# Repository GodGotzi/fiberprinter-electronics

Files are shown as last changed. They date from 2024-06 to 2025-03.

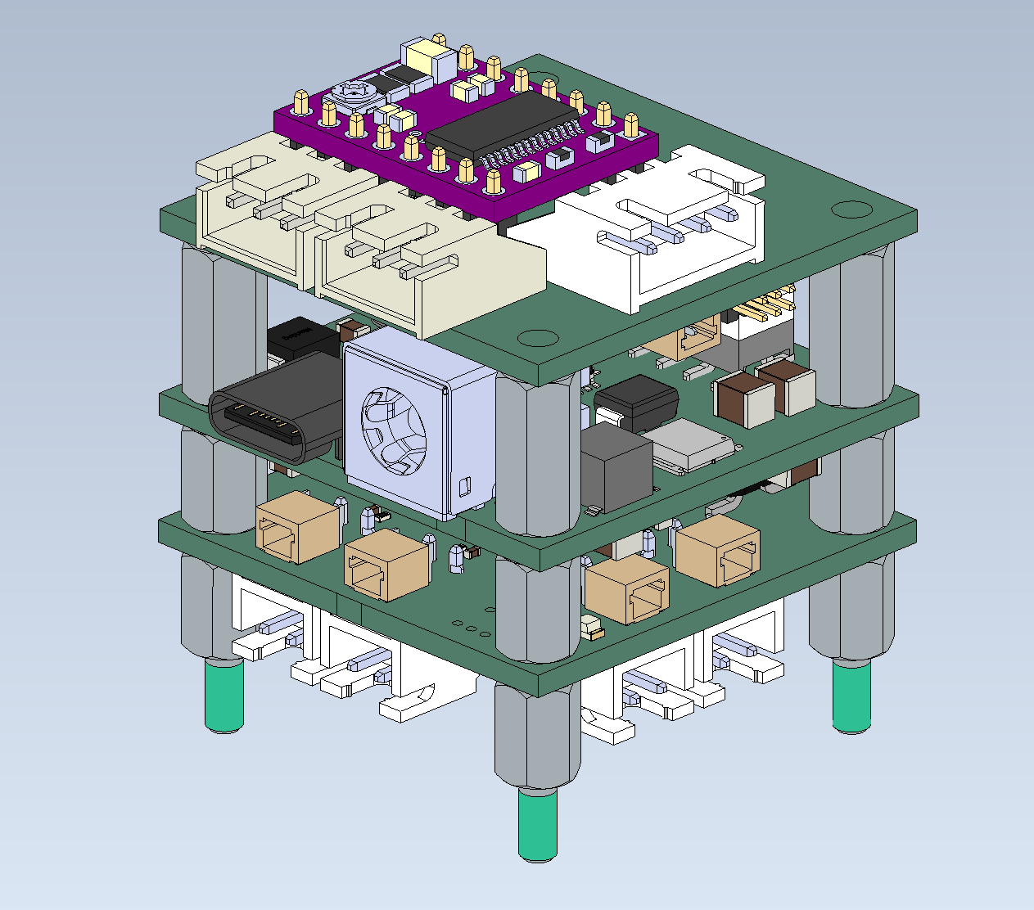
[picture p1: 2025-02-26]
2nd-mainboard-pcb/cad/bilder/simple.png

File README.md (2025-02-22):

# Fiberprinter Electronics

Dieses Repository enthält die Elektronikentwicklung für den faserverlegenden 3D-Drucker, der im Rahmen einer Diplomarbeit an der HTBLA Kaindorf entwickelt wird. Die Elektronik umfasst sowohl die Steuerung der Druckkopffunktionen als auch die Anbindung an das Hauptsystem mittels eines Raspberry Pi mit **Klipper-Firmware**.

## 📌 Projektübersicht

Das Ziel dieses Projekts ist die Entwicklung einer modularen und effizienten Steuerung für den Druckkopf, die über eine eigenentwickelte Platine mit einem **ATmega328** realisiert wird. Diese übernimmt spezifische Aufgaben, die über das Hauptsystem des Druckers nicht direkt gesteuert werden.

## ⚙️ Hauptkomponenten

### 1️⃣ **Steuerungshardware**
- **Raspberry Pi** mit Klipper-Firmware zur übergeordneten Steuerung
- **Eigenes Mainboard mit ATmega328** zur Ansteuerung folgender Komponenten:
  - Lüfter
  - BL Touch (Autoleveling-Sensor)
  - Servo
  - Schrittmotor
  - Temperatursensoren
- **Breakout-Board für den ATmega2560**, das Test- und Messpunkte sowie einen Bootloader enthält
- **FT232RL** als USB-to-Serial-Adapter für die Kommunikation mit dem ATmega2560
- **Reset-Button** zur einfachen Rücksetzung des Systems

### 2️⃣ **Firmware & Kommunikation**
- Der **ATmega328** wird von der Klipper-Firmware auf dem Raspberry Pi über USB angesprochen
- Kommunikation erfolgt über **serielles Protokoll**
- Entwicklung einer **angepassten Firmware für den ATmega328**, um die spezifischen Druckkopf-Funktionen auszuführen

### 3️⃣ **Software**
- Python-Skript zur **Integration der Steuerung in Klipper**
- Implementierung eines Protokolls zur **Steuerung der Hardware aus Klipper heraus**
- Zusammenarbeit mit der **Slicing-Software**, um die gezielte Faserverlegung zu ermöglichen

## 🛠️ Entwicklungsteam

- **Jan Traußnigg** – Elektronikdesign & Firmware
- **Nico Hütter** – Konstruktion, Aufbau & Testung
- **Elias Gottsbacher** – Slicing-Software & Software-Integration

## 📜 Lizenz

Dieses Projekt steht unter der **MIT-Lizenz**. Weitere Details sind in der Datei `LICENSE` zu finden.

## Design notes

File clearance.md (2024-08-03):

Sure, let's define both the minimum clearance and track width for each voltage and data line, adhering to industry standards for safe and reliable operation in a controlled environment (within a housing).

### 1. **12V DC**
- **Minimum Clearance:** 0.2 mm
- **Minimum Track Width:** 0.3 mm
- **Argument:** For 12V DC circuits, a clearance of 0.2 mm ensures safety against short circuits and arcing according to IEC 60950-1. The track width of 0.3 mm is chosen to handle the current typically associated with 12V DC circuits, providing a balance between electrical performance and manufacturability.

### 2. **5V DC**
- **Minimum Clearance:** 0.2 mm
- **Minimum Track Width:** 0.2 mm
- **Argument:** For 5V DC circuits, maintaining a 0.2 mm clearance aligns with IEC 60950-1 standards, ensuring electrical safety. A track width of 0.2 mm is sufficient for the low current levels typically found in 5V circuits, ensuring reliable operation and ease of manufacturing.

### 3. **3.3V DC**
- **Minimum Clearance:** 0.1 mm
- **Minimum Track Width:** 0.15 mm
- **Argument:** For 3.3V DC circuits, a 0.1 mm clearance is appropriate given the low voltage and controlled environment, adhering to industry norms. The track width of 0.15 mm is adequate for the lower current levels in 3.3V circuits, ensuring signal integrity and reliability.

### 4. **5V I2C Data**
- **Minimum Clearance:** 0.2 mm
- **Minimum Track Width:** 0.2 mm
- **Argument:** For I2C data lines operating at 5V, a 0.2 mm clearance ensures minimal risk of crosstalk and signal interference, crucial for reliable communication. The track width of 0.2 mm supports the low current typically associated with data lines while maintaining signal integrity.

### 5. **5V Differential I2C Data**
- **Minimum Clearance:** 0.2 mm
- **Minimum Track Width:** 0.2 mm (each line in the pair)
- **Argument:** For differential I2C data lines at 5V, a 0.2 mm clearance helps prevent crosstalk between pairs and other signal paths. Each line in the differential pair should have a track width of 0.2 mm to ensure consistent impedance and reliable differential signaling.

### Summary of Chosen Clearances and Track Widths:
- **12V DC:** 
  - **Clearance:** 0.2 mm
  - **Track Width:** 0.3 mm
- **5V DC:**
  - **Clearance:** 0.2 mm
  - **Track Width:** 0.2 mm
- **3.3V DC:**
  - **Clearance:** 0.1 mm
  - **Track Width:** 0.15 mm
- **5V I2C Data:**
  - **Clearance:** 0.2 mm
  - **Track Width:** 0.2 mm
- **5V Differential I2C Data:**
  - **Clearance:** 0.2 mm
  - **Track Width:** 0.2 mm (each line in the pair)

These specifications are chosen to ensure the minimum necessary sizes for clearances and track widths, balancing safety, performance, and manufacturability for your design within a controlled environment.

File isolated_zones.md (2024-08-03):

### Potential Risks of Isolated Copper Fills on a PCB

1. **Electromagnetic Interference (EMI):**
   - Acts as antennas, increasing EMI emissions.
   - Can interfere with the PCB and nearby electronic devices.

2. **Signal Integrity Issues:**
   - Causes impedance mismatches and reflections.
   - Leads to signal integrity problems.

3. **Thermal Management Problems:**
   - Creates hot spots or uneven thermal distribution.
   - Can cause overheating of components.

4. **Manufacturing Defects:**
   - Problems with etching and plating processes.
   - May result in incomplete etching or plating voids.

5. **Electrochemical Migration:**
   - Accumulation of moisture and contaminants.
   - Increases the risk of short circuits.

6. **Mechanical Stress:**
   - Creates mechanical stress points, especially during thermal cycling.
   - Can lead to delamination or cracking.

7. **Increased Capacitance:**
   - Introduces unwanted capacitance.
   - Affects performance of high-speed signals and RF circuits.

8. **Potential for Floating Copper:**
   - Unconnected copper fills can float electrically.
   - Leads to unpredictable circuit behavior.

### Mitigation Strategies
- Ensure copper fills are properly connected to a reference plane (e.g., ground).
- Carefully consider the placement of copper fills in the PCB design.
- Conduct thorough design reviews and simulations to identify and address potential issues before manufacturing.

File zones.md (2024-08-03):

### Summary of Filled Zones in PCB Design:

**Filled Zones Overview:**
- **Definition:** Areas on a PCB layout filled with copper, typically used for ground planes, power planes, and large conductive areas.
- **Purpose:** Improve electrical performance, thermal management, and mechanical strength of the PCB.

**Importance in EMI Reduction:**
1. **Minimizing Loop Areas:**
   - Ground planes provide a low-impedance return path for signals, reducing loop areas and radiated EMI.
2. **Providing Shielding:**
   - Ground planes act as shields, blocking external EMI and preventing internal signals from radiating out.
3. **Improving Signal Integrity:**
   - Maintain consistent impedance for high-speed signals and reduce noise.
4. **Reducing Crosstalk:**
   - Continuous reference planes help minimize crosstalk between adjacent signal traces.

**Best Practices for Using Filled Zones:**
- **Use Solid Ground Planes:**
  - Prefer solid ground planes for maximum EMI reduction and signal integrity.
- **Keep Signal and Return Paths Close:**
  - Route high-speed signals over continuous ground planes.
- **Utilize Stitching Vias:**
  - Connect ground planes on different layers with stitching vias to reduce impedance.
- **Avoid Splits in Ground Planes:**
  - Ensure ground planes are not interrupted by signal traces or other discontinuities.
- **Place Decoupling Capacitors:**
  - Position decoupling capacitors close to power pins of ICs to mitigate high-frequency noise.
- **Isolate Noisy Components:**
  - Keep noisy components away from sensitive analog circuits and use ground planes to shield them.

### Recommendations:
- **For EMI Reduction:**
  - Use solid copper pours for ground planes.
  - Ensure continuous and unbroken ground planes beneath signal traces.
  - Implement stitching vias to enhance grounding and reduce EMI.
- **For Overall Performance:**
  - Combine ground and power planes to create a stable electrical environment.
  - Maintain proper clearance settings and use thermal reliefs for component pads.

By implementing these practices, you can significantly enhance the EMI performance and overall functionality of your PCB designs.

TO FIX THE ERROR "ISOLATED COPPER FILLS" TURN ON "REMOVE ISLANDS" IN FILLING ZONE.

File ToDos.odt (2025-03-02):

ToDo

Wie viel ohm hat motor

Is mosfet zu langsam?

Max strom 100mA -> wenn man einfach einen mosfet mit max 1a nimmt wird der Gate kondensator auch kleiner dann schaltet er schneller

Sensor werte 1. Ordnung reicht normal, sonst gibt’s ja eh die möglichkeit vom digitalen filtern no

Jede sekunde messwert nehmen

Equididante sampling rate

Wird stepper schritte verlieren? Wie kurz werden die schritte?

Worst case: faser fängt 1mm zu spät an

Die freien general purpose io pins nach außen legen

Mit oszilloskopo pwm ausgang testen

Checken ob bauteile verfügbar sind jlcpcb

Stencil

Display raspi

vorschlag

wir haben 80er serie smd bauteile in der schule zur verfügung

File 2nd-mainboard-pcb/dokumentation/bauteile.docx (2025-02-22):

Stückliste Bestellung 15.1.2025

USB-C Stecker: 2x

https://www.digikey.at/en/products/detail/gct/USB4085-GF-A/9859662

Atmega 328P

https://www.digikey.at/de/products/detail/microchip-technology/ATMEGA328PB-AU/5638812

USB/Serial Wandler

https://www.digikey.at/en/products/detail/ftdi-future-technology-devices-international-ltd/ft232rl-reel/1836385

optional 5V 3V3 converter

https://www.digikey.at/de/products/detail/mornsun-america-llc/F0503XT-1WR3-TR/13617558

LED

https://www.digikey.de/en/products/detail/w%C3%BCrth-elektronik/151031VS06000/4489988

switch

https://www.digikey.de/en/products/detail/panasonic-electronic-components/EVQ-Q2Y02W/762910

oscillator

https://www.digikey.at/de/products/detail/ecs-inc/ECS-160-18-4X-CKM/12349451

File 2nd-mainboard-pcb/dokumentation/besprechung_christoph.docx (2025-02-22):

Besprechung christoph scheucher

Schaltfrequenzen wegpuffern

Lötpdastellen fuer ios und andere

Atmega328 – aurct-nd

Okay kleiner neuanfang: was k“habe ich heute mit dem scheucher geredet? Wir haben angefangen dmait, dass er mir seine platinbe, die er f“ur den robocuip entwickelt hat gezeigt hat, mir tipps gegeben hat und betont hat, dass ich mich bei fragen jederzeit bei ihm melden k“onnte. Sehr nett

Kommen wir aber gleich zu den tipps, an die ich mich erinnern m“ochte. Erstens: w“ahle verschieden kondensatoren gro:ossen aus, da sie unterschiedliche frequenzen puffern. Versuche sie so zu w’halen, dass die deine schaltfrequenz wegpuffern. Elektrolyt kondensatoren werden warm, deswegen hat er von diesen keine verwendet. Ausserdem hat mer mir empfohlen, anschluesse die mir zur verf“ugung stehen, welche ich aber in meinem projekt nicht unbedingt brauche trotzdem als l“otpad auszuf“uhren um diese f“ur sp“atere optionale debugging zwecke benutzen zu k“onnen.

Meine n“achsten schritte werden jetzt jedenfalls sein 12v leistung zum mainboard mitzuliefern, wie auch immer das realisiert wird. Eventuell kann usb-c sogar 12v „ubergeben, da muss vorher halt geschaut werden wie das funktionieren k“onnen. Ausserdem muss ich mir den strom anschauen, welcher der raspberry pi liefert und welchen verbrauch ich am druckkopf habe. Dadurch, dass ich jetzt ja auch noch einen schrittmotor am druckkopf ansteuern muss „andern sich ein paar dinge. Zudem, k“onnte idch vielleicht sogar 5v zu 12v konvertieren? Wenn nicht, k“onnte es kompliziert werden, dann muss ich schauen ob der raspberry pi einen 12v ausgang hat und mit welchem kabel ich das hinauf verbinde. Die fans k“onnten auch 12v gebrauchen, ist aber kein unbedingtes muss

Auf jeden fall sollte ich als alternative 5v fans heraussuchen.

Dann sollte ich schauen, ob der schrittmotor eh mit einem normalen motor driver angesteuert werdenkann. Dann sollte ich nico um die neuste konstruktion bitten, um einzusehen, wo ich die platine montieren kann und wie viel platz ich habe. Zudem ob odie headerpins f“ur die fans 01x02 geiignet sind tht vertical/horizontal oder ob da vielleicht sogar smd m“oglich w“are. Dann m“ussten wir halt die temperatursensor kabeln neu konfektionieren, aber das w“ar ja okay.

Scund ausserdem kann ich mich sollte ich mich nach eine mbeschleunigungssensor umschauen.

Offen bleibt zudem die frage, ob wir das heat element dann auch mit der printhead pcb ansteuern oder vom mainboard damit zum printhead gehen. Wenn ja, dann k“onnten wir gleich nach einer l“sung suchen bei der wir die leitung f’ur das heatbreak und die 12v leitung mit einem kabel rauf verbinden.

Zudem sollte ich ein neues kicad project f“ur das raspi shield anfertigen, da es sich jett viel vom i2c rapsi shield unterscheidet.

Trotzdem sollte ich einen stepper driver noch auf dem raspi shield verbauen, nur um sicher zu gehen…. Da hab ich sowieso platz.

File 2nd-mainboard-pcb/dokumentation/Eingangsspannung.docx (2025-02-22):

Eingangsspannung-Kalkulierung

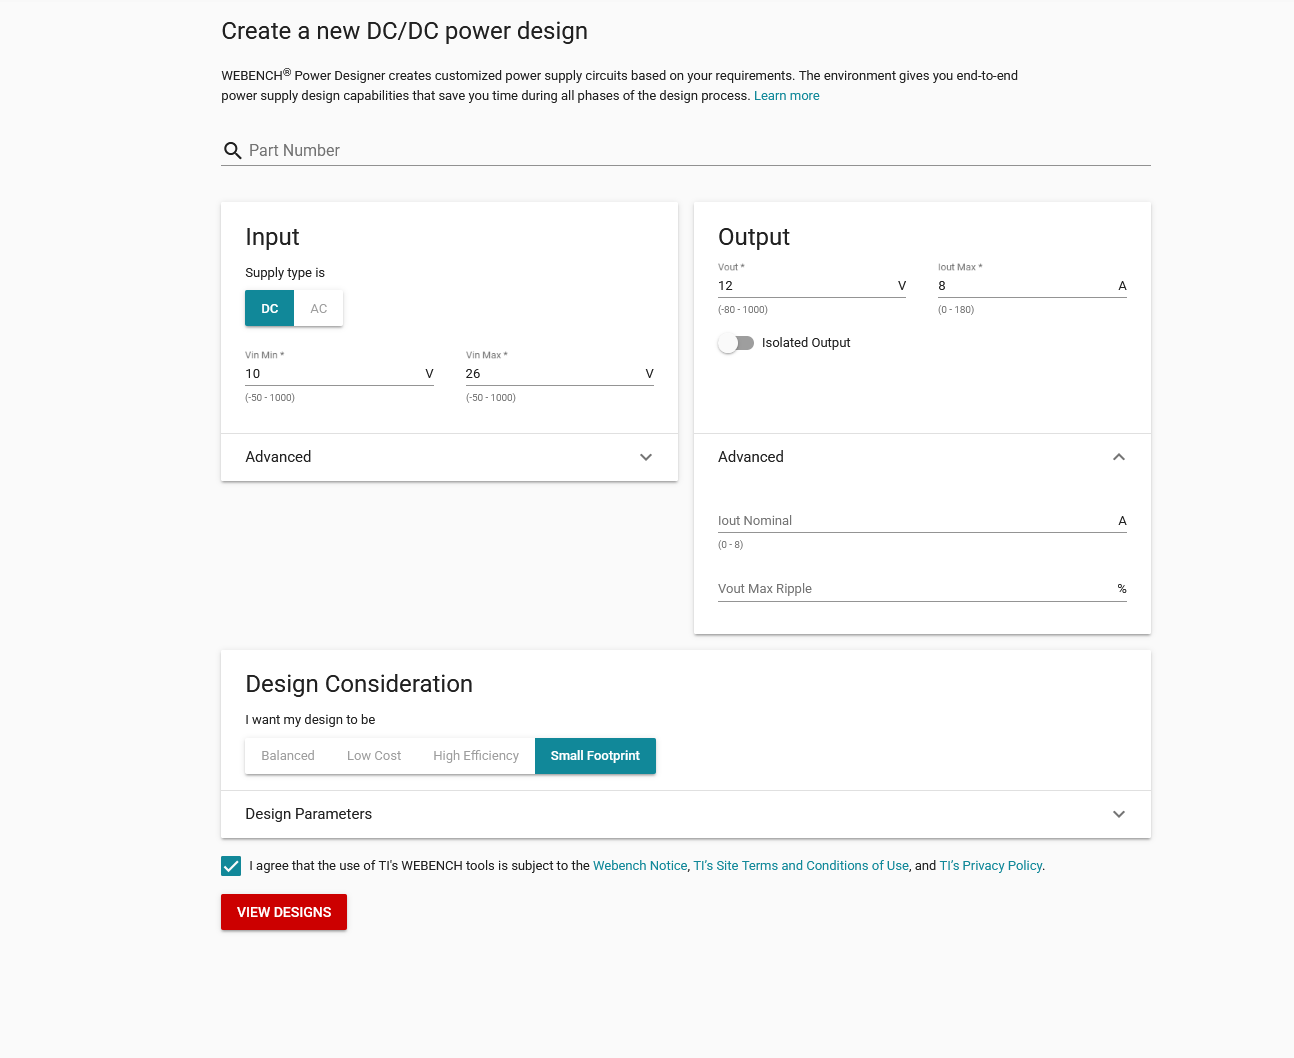
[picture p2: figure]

https://webench.ti.com/power-designer/switching-regulator?powerSupply=0

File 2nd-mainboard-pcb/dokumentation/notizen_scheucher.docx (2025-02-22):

Zusammenfassung der Notizen

Notizen

1. Gespräch mit Scheucher:
  - Präsentation seiner Platine für RoboCup.
  - Hinweise und Angebot für Unterstützung bei Fragen.
  - Freundliche Atmosphäre.
2. Wichtige Tipps von Scheucher:
  - Kondensatorwahl:
    - Unterschiedliche Größen puffern verschiedene Frequenzen.
    - Kondensatoren sollten auf die Schaltfrequenz abgestimmt sein.
    - Vermeidung von Elektrolytkondensatoren wegen Wärmeentwicklung.
  - Debugging-Optionen:
    - Zusätzliche Lötpads für Anschlüsse, auch wenn diese zunächst nicht benötigt werden.

To-Do-Liste

1. Elektrische Versorgung:
  - 12V Versorgung zum Mainboard integrieren.
  - Überprüfen, ob USB-C 12V übertragen kann.
  - Alternativen prüfen: 5V zu 12V Konverter oder direkte 12V vom Raspberry Pi.
2. Verbrauchsanalyse:
  - Strombedarf des Raspberry Pi und des Druckkopfs analysieren, insbesondere mit zusätzlichem Schrittmotor.
3. Komponentenwahl:
  - Lüfter auf 5V-Basis als Alternative heraussuchen.
  - Prüfen, ob der Schrittmotor mit einem Standard-Motortreiber betrieben werden kann.
4. Designanpassung:
  - Aktuelle Konstruktion von Nico einholen:
    - Platz für die Platine.
    - Ausrichtung und Position der Header-Pins (01x02, THT vertikal/horizontal, SMD möglich?).
5. Temperatursensorkabel:
  - Überarbeitung und Konfektionierung.
6. Sensoren:
  - Recherche nach einem Beschleunigungssensor für den Druckkopf.
7. Wärmeeinbindung:
  - Klären, ob das Heizelement über die Printhead-PCB oder direkt vom Mainboard angesteuert wird.
8. Platinenerstellung:
  - Neues KiCad-Projekt für das Raspberry Pi Shield anlegen:
    - Anpassungen an den veränderten Anforderungen (Unterschiede zum I2C-Shield).
    - Einbindung eines Stepper Drivers auf dem Shield.

Zusammenfassung der Herausforderungen

- Integration zusätzlicher Komponenten (Schrittmotor, Lüfter).
- Sicherstellung der elektrischen Versorgung (12V und 5V).
- Platz- und Designanforderungen klären.
- Debugging und erweiterte Funktionalität durch Zusatzoptionen berücksichtigen.

Die strukturierte Planung ermöglicht es, die nächsten Schritte effizient zu koordinieren und gezielt an den Herausforderungen zu arbeiten.

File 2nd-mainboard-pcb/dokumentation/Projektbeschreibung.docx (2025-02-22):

# Projektbeschreibung

Druckkopf für einen 3D Drucker. Am Druckkopf sind angebracht:

- 4 Lüfter
- 1 Servo
- 1 Schrittmotor
- 4 Temperatur sensoren

Zur Ansteuerung des Druckkopfes wird ein Raspberry Pi verwendet, auf welchem die Firmware Klipper installiert ist. Dieser kommuniziert mit einer USB Verbindung mit dem Mainboard des 3D Druckers.

Am Druckkopf ist ein zweites eigenentwickeltes Mainboard, das auch mit USB zum Raspbberry Pi verbunden ist.

Auf dem zweiten Mainboard ist der ATMEGA328P-AN, um das Schaltbild zu entwickeln werden folgende schritte gemacht:

### 1. Stromversorgung

- Spannungsregler: Raspberry Pi12V -> Spannungsregler, um die Spannung für den ATmega328 auf 5V zu senken
- Bypass-Kondensatoren: stabile Stromversorgung -> Kondensatoren (z. B. 0.1 µF und 10 µF) nahe dem ATmega328.

### 2. ATmega328 Schaltung

- Taktgeber: Quarz (z. B. 16 MHz) mit zwei 22pF-Kondensatoren, um stabil zu laufen
- Reset-Pin: Reset-Pin mit Taster und einem Pull-up-Widerstand (z. B. 10 kΩ), damit du den ATmega328 manuell zurücksetzen kannst.

### 3. USB-Kommunikation

- Um eine Verbindung zum Raspberry Pi über USB herzustellen, benötigst du einen USB-to-Serial-Wandler MCP2200
- Verbinde die UART-Pins (RX/TX) des ATmega328 mit dem Wandler.

### 4. Ansteuerung der Komponenten

- Lüfter: Die 4 Lüfter benötigen entweder PWM-Pins des ATmega328
- Servo: Für den Servo brauchst du einen PWM-Ausgang.
- Schrittmotor: Zur Steuerung eines Schrittmotors DRV8825
- Temperatursensoren: Die 4 Temperatursensoren (vermutlich NTCs oder Thermistoren) können an analogen Eingängen des ATmega328 angeschlossen werden.

### 5. Bauelemente und Verbindungen

- Pull-up/Pull-down Widerstände: Wenn du digitale Eingänge verwendest, vergiss nicht, entsprechende Widerstände (typischerweise 10kΩ) hinzuzufügen.
- Schutzdiode: Du kannst eine Schutzdiode (z. B. 1N4007) einbauen, um den ATmega vor Rückstrom zu schützen.

### 6. Kommunikation mit dem Raspberry Pi

- USB-Kabel: Stelle sicher, dass du die USB-Verbindung vom ATmega328 zum Raspberry Pi korrekt verdrahtest. Die USB-Leitung muss über den USB-zu-Seriell-Wandler laufen.

### 7. PCB Design

- Nachdem du den Schaltplan erstellt hast, musst du entscheiden, wie du das PCB layouten möchtest, um die Verbindungen zwischen den Bauteilen herzustellen.

Offene Fragen

Kann man den Atmega auch über die USB Schnittstelle programmieren?

Muss die Kommunikation über USB gehen?

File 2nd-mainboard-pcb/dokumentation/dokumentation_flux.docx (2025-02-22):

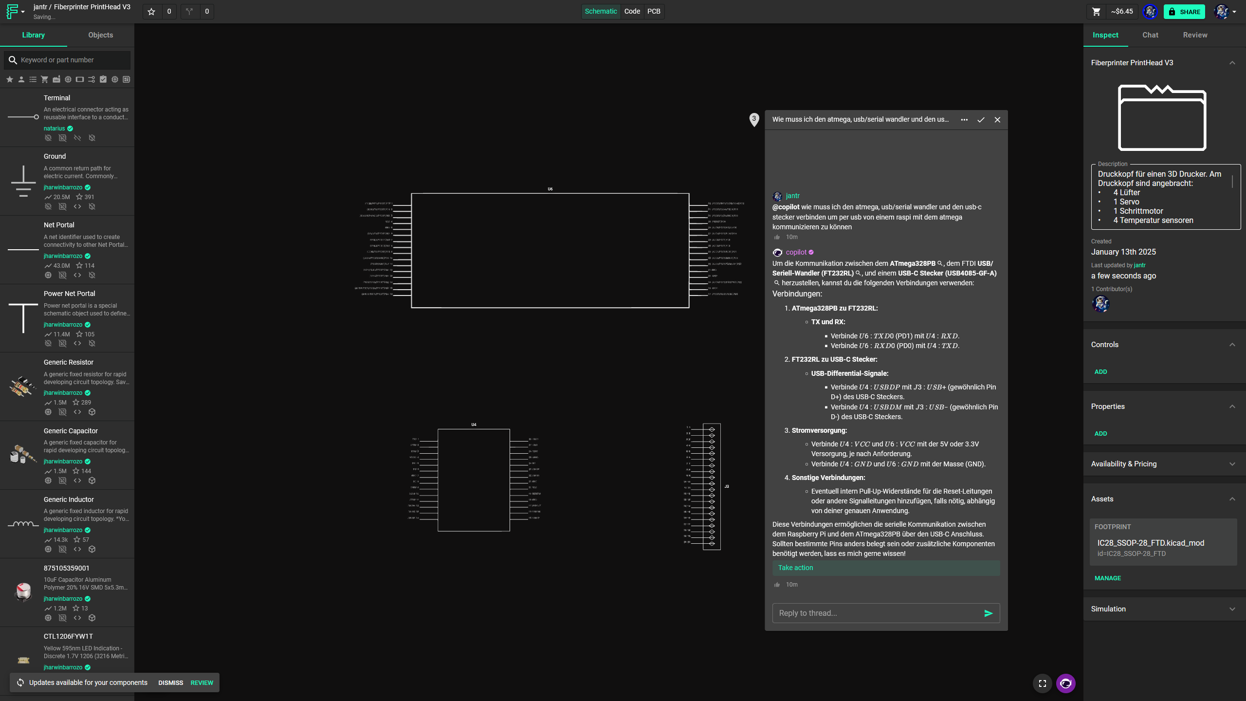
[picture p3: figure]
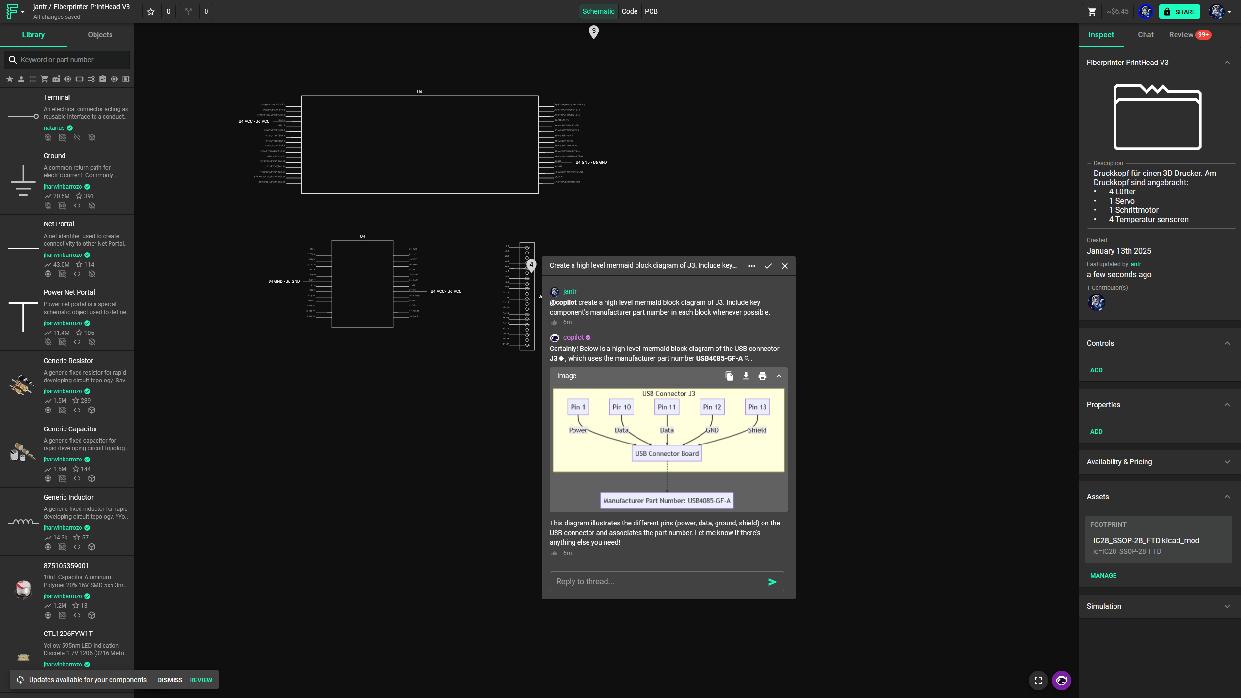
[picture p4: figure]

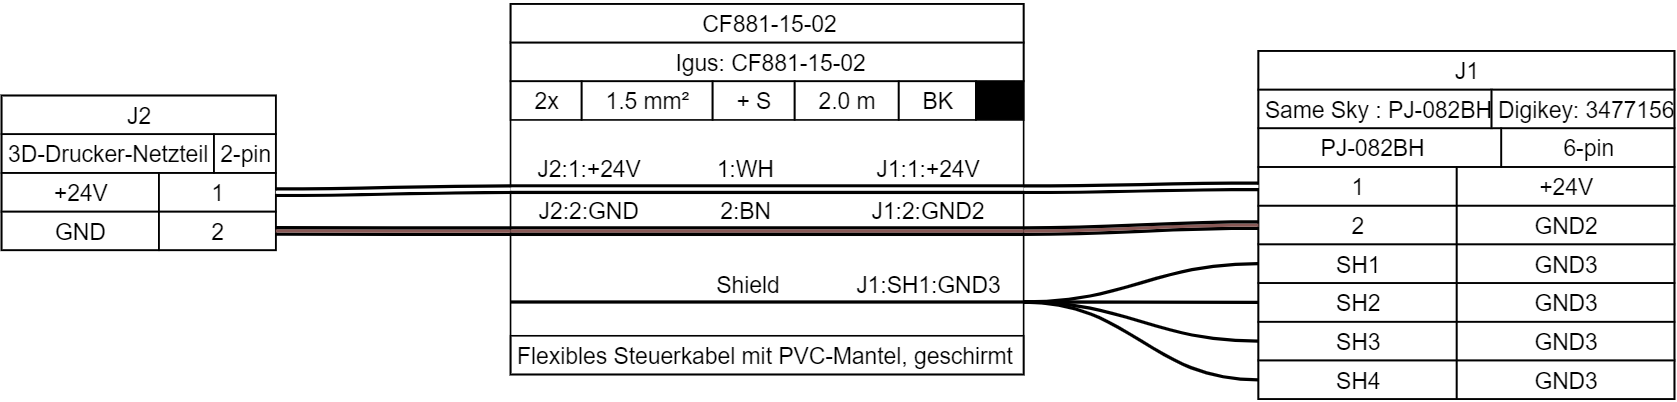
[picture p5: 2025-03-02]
usbstick/elektronik/wireviz/Verbindung_Platine_3D_Drucker.png

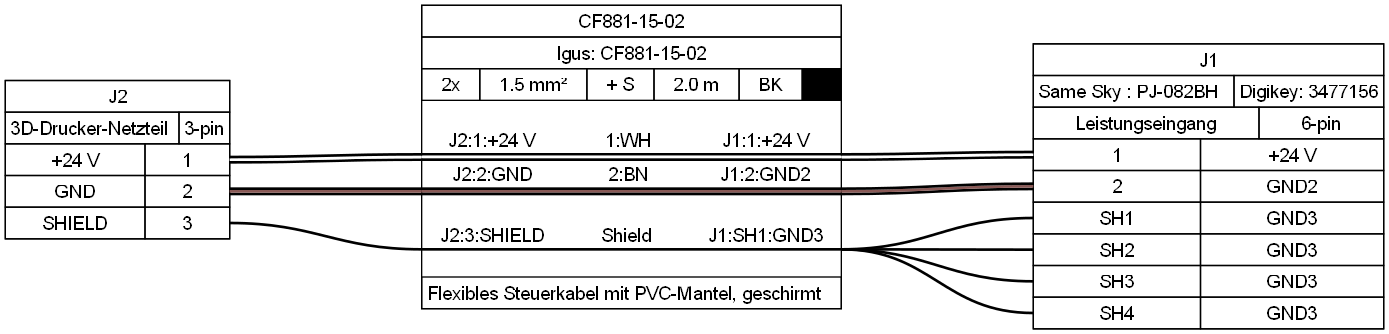
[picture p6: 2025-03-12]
2nd-mainboard-pcb/wireviz/png/platine_drucker.png

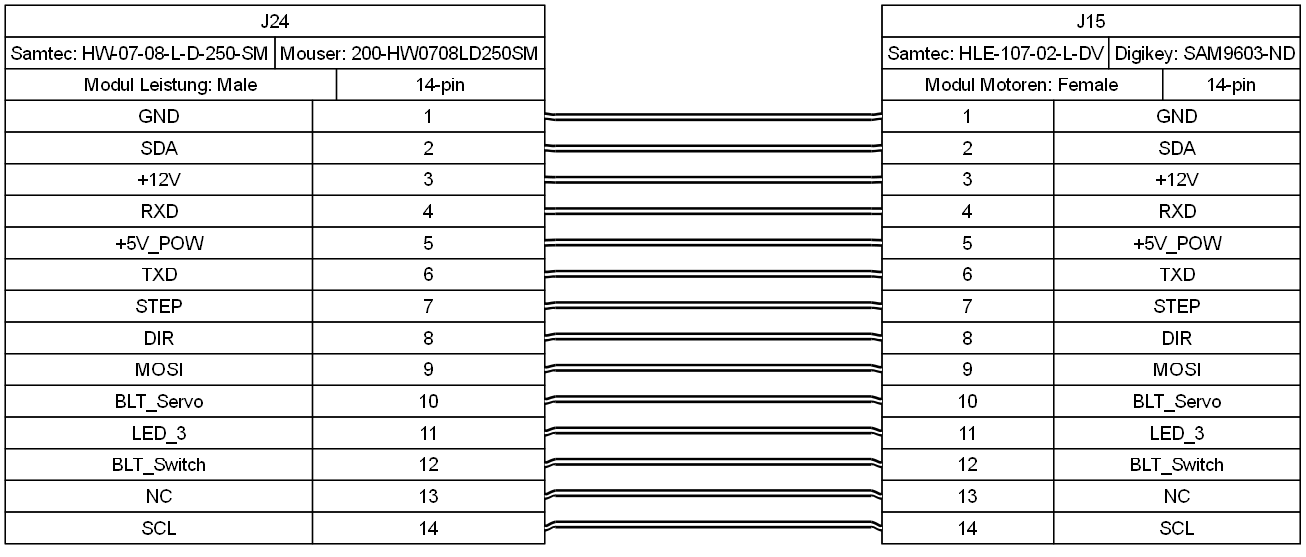
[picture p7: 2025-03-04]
usbstick/elektronik/wireviz/leistung_motoren.png

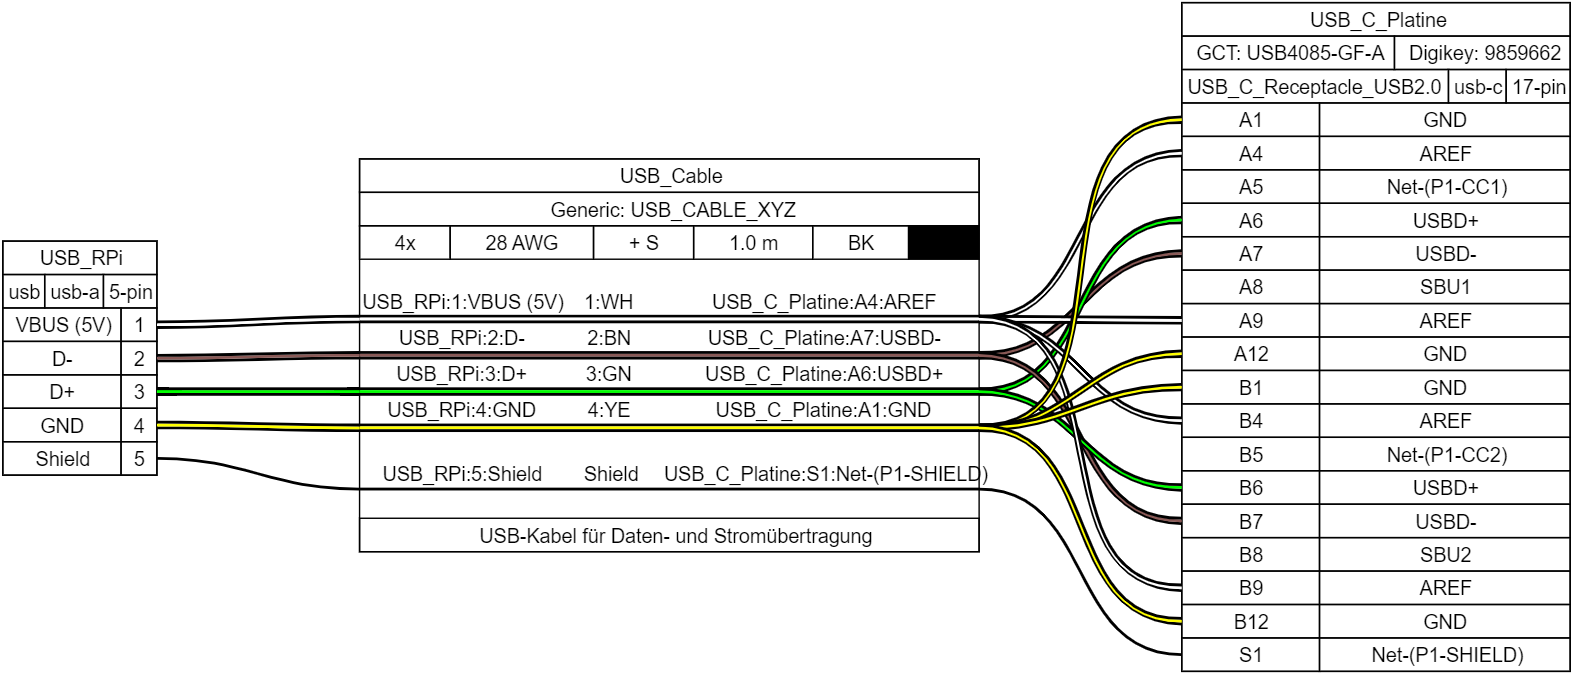
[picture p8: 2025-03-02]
usbstick/elektronik/wireviz/Verbindung_Platine_Raspi.png

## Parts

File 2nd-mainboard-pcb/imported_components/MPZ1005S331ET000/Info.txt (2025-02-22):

Eine Ferritperle dient dazu, hochfrequente Störungen auf der Versorgungsleitung zu unterdrücken, indem sie bei diesen Frequenzen eine hohe Impedanz aufweist. Dadurch wird das Rauschen reduziert und die Stabilität der Versorgungsspannung im System verbessert.

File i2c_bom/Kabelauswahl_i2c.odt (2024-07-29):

Variante 1: Kabel auf eBay/Amazon bestellen (Kein Datenblatt) und Buchse dazukaufen

Vorteil: Einheitliches Buchsensystem (jst ist übliche 3D Drucker Buchse), schnelle Lieferung

Nachteil: Nicht konfektioniert, Buchse muss angelötet/gecrimped werden

Kabelauswahl

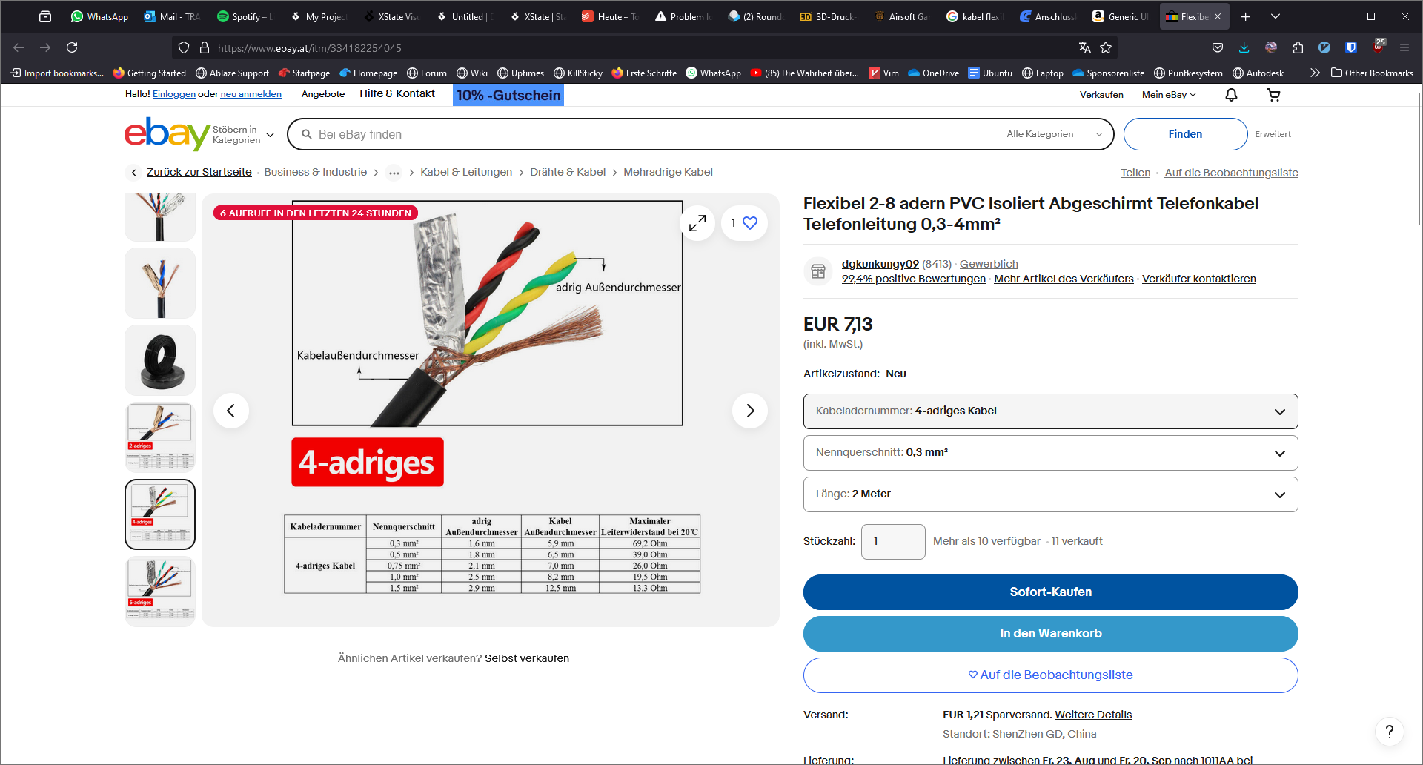
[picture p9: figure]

https://www.ebay.at/itm/334182254045

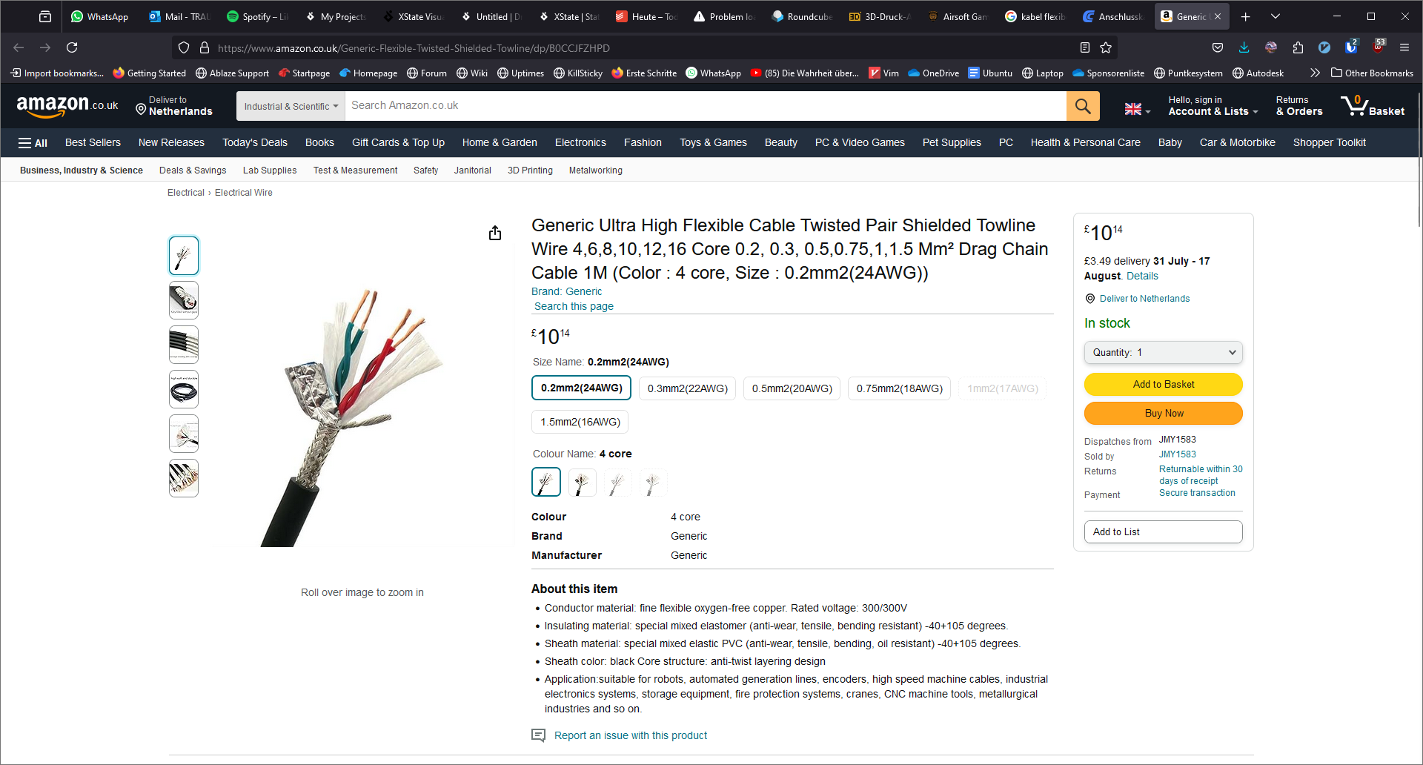
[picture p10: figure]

https://www.amazon.co.uk/Generic-Flexible-Twisted-Shielded-Towline/dp/B0CCJFZHPD

Buchsenauswahl

Normale Buchse Set

Nachteil: Nicht gewinkelt, erschwert den Einbau bei Platine

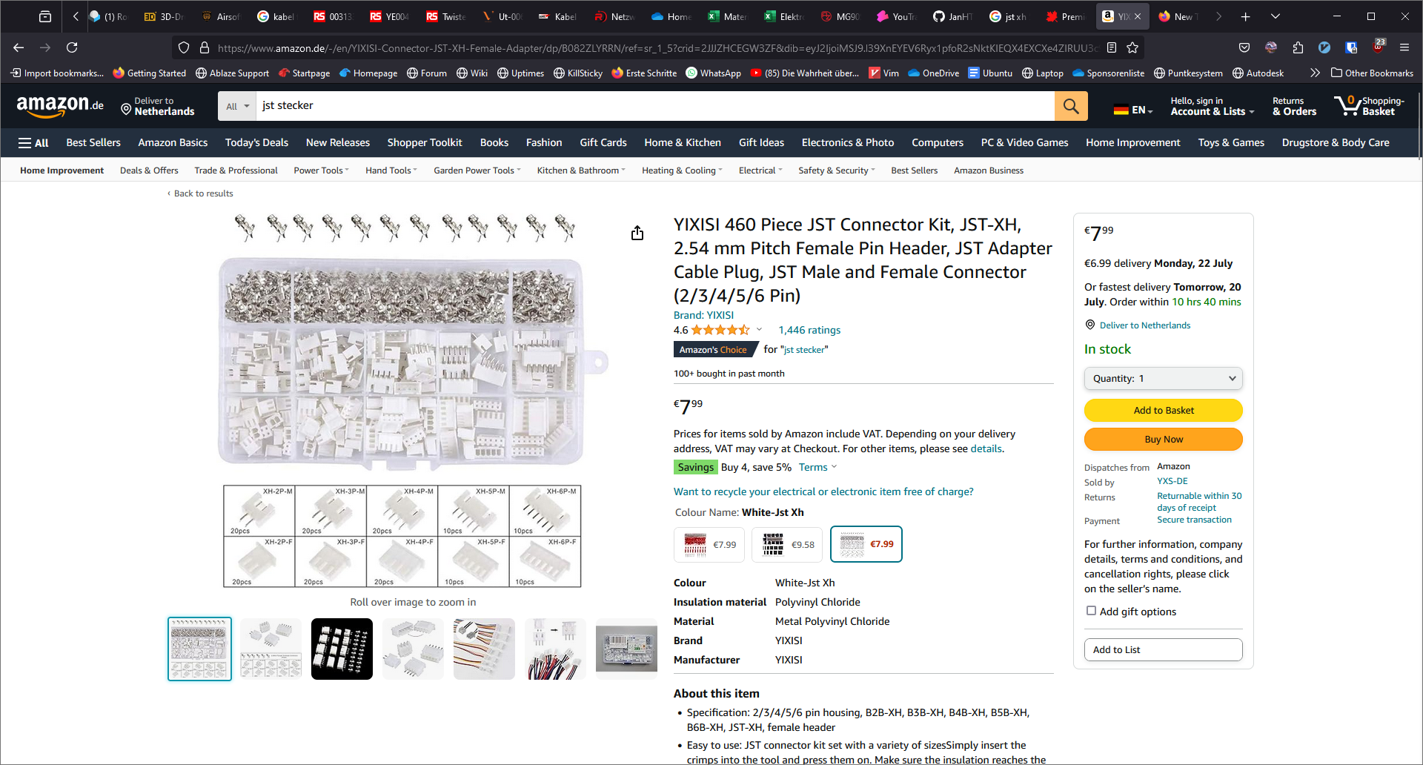
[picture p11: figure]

https://www.amazon.de/-/en/YIXISI-Connector-JST-XH-Female-Adapter/dp/B082ZLYRRN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

Problem: 99% der rechtwinkligen Buchsen haben 2mm Pitch und wir möchten 2,54mm Pitch

Warum 2,54mm: standart Rastermaß ist 2,54, man kann normale breadboards und jumper kabeln verwenden

Lösung 1: Eine Seite auf Ebay bietet das an (wirkliche die einzige die wir gefunden habn)

Problem: Versand nicht nach Österreich

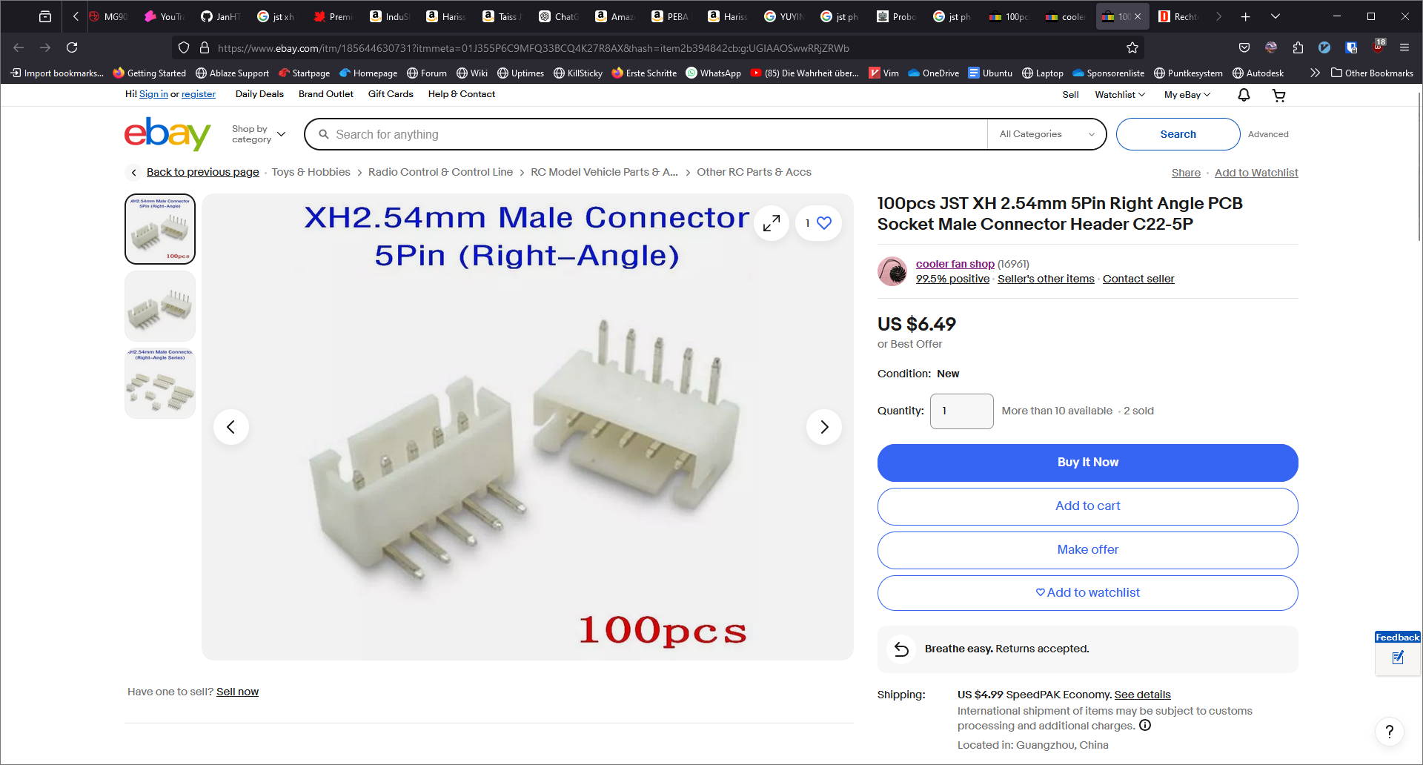
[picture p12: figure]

https://www.ebay.com/itm/185644630731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

Lösung 2: gewinkelte Jumper verwenden als Buchse für Platine

Anmerkung: Funktionalität muss erst getestet werden

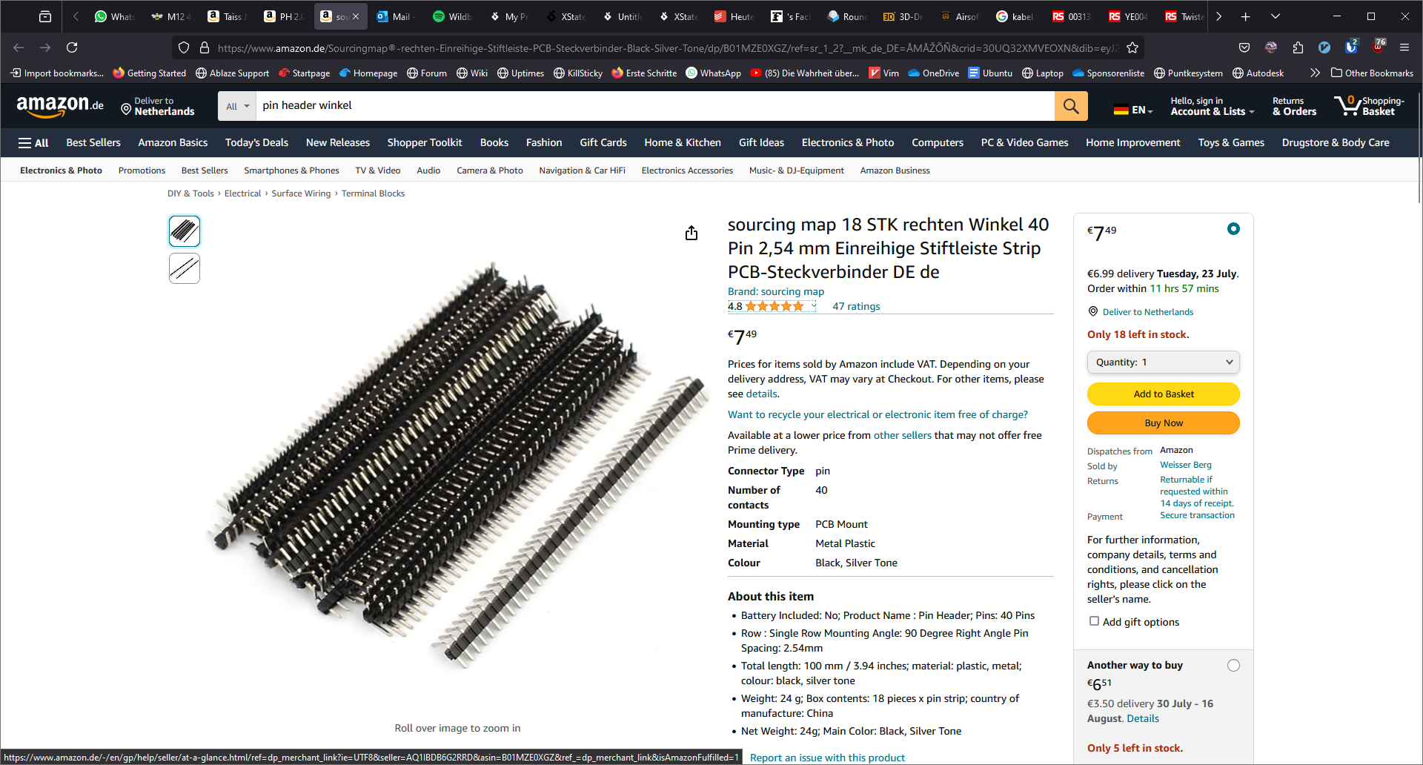
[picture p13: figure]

https://www.amazon.de/Sourcingmap%C2%AE-rechten-Einreihige-Stiftleiste-PCB-Steckverbinder-Black-Silver-Tone/dp/B01MZE0XGZ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 (https://www.amazon.de/Sourcingmap®-rechten-Einreihige-Stiftleiste-PCB-Steckverbinder-Black-Silver-Tone/dp/B01MZE0XGZ?__mk_de_DE=ÅMÅŽÕÑ)

Lösung 3: 2mm Pitch verwenden

Vorteil: Set, wo alles dabei ist (gewinkelte Buchse und gerade Stecker)

Nachteil: Nicht im standard-Rastermaß

Anmerkung: Irgendwo muss das aber Norm sein, so viel wie 2mm pitch winkel buchsen wir hier gefunden haben

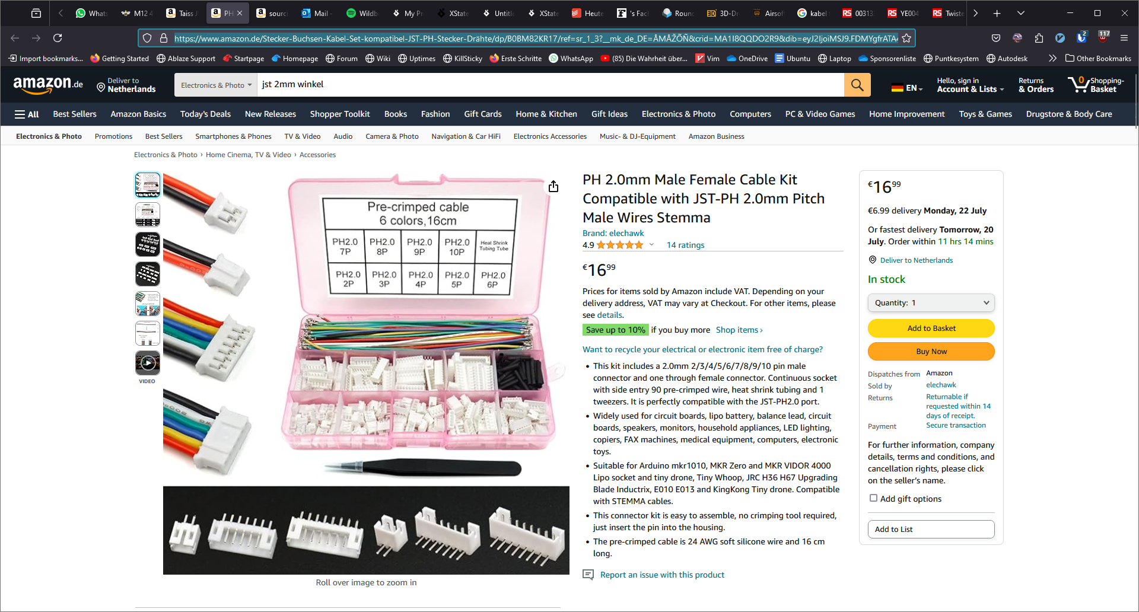
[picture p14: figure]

https://www.amazon.de/Stecker-Buchsen-Kabel-Set-kompatibel-JST-PH-Stecker-Dr%C3%A4hte/dp/B0BM82KR17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

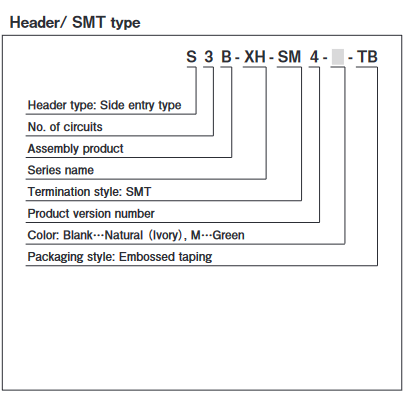
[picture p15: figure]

Variante 2: Fertiges Kabel mit Stecker bestellen

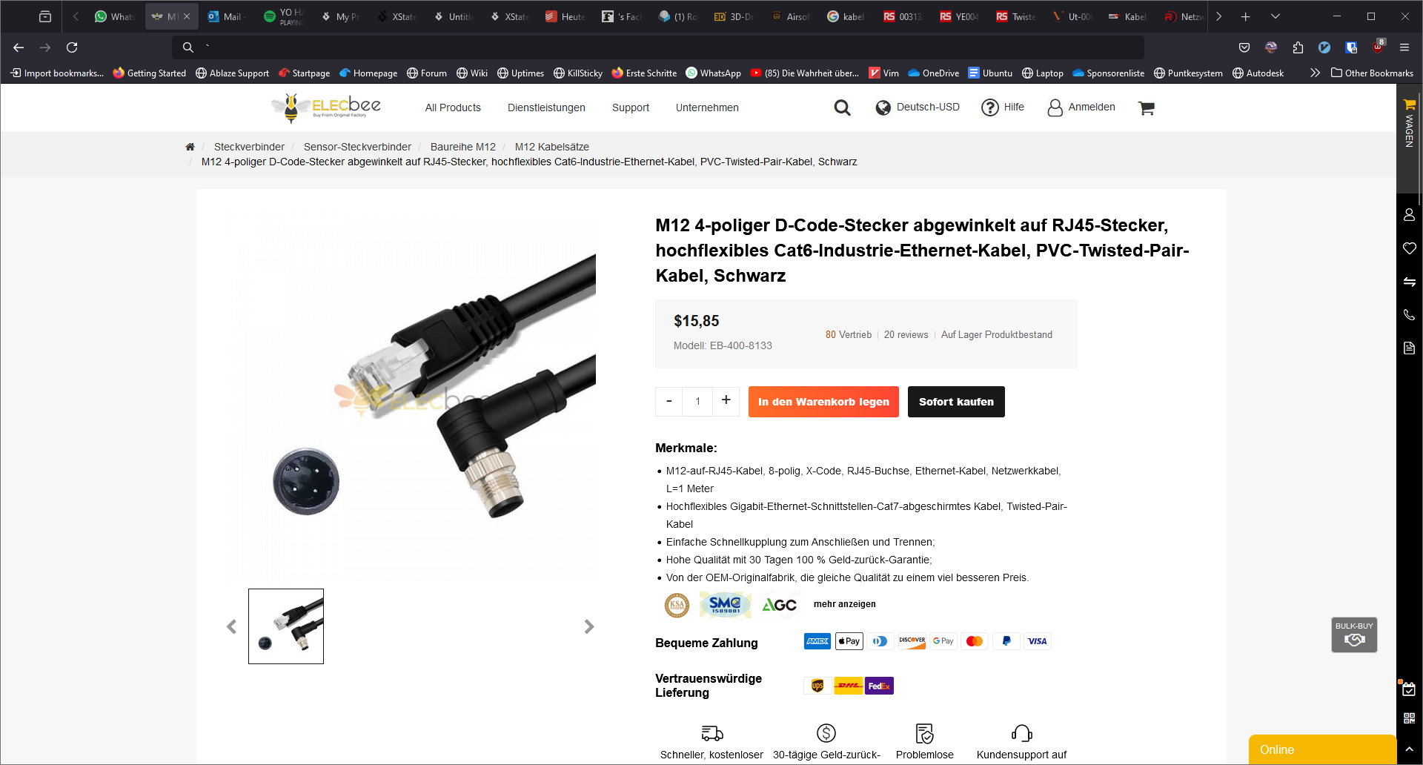
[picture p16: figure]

https://www.elecbee.com/de-54283-m12-4-pin-d-code-male-angled-to-rj45-male-high-flex-cat6-industrial-ethernet-cable-pvc-twisted-pair-cable-black

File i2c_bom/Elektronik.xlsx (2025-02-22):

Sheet: DifI2C
Alternative | Bezeichnung | Kategorie | Seriennummer | Beschreibung | Stromverbrauch in A | Lieferant | URL | Preis/Stk. | Stückzahl | Gesamtpreis | Gesamt-Real-Sum | €83.00 | Gesamt-Sum | €243.06
 | Schrittmotor | Aktor | 14HM08-0504S | Bipolar, 5Ncm, 35x35x20, 90g | Angesteuert v. Mainboard | Stepperonline | https://www.omc-stepperonline.com/de/nema-14-bipolar-0-9deg-5ncm-7-08oz-in-0-5a-5v-35x35x20mm-4-draehte-14hm08-0504s | €9.91 | 1 | €9.91
 | Schrittmotor-Treiber | Aktor | DRV8825 | Bipolarer SM, full step to 1/32 step |  | AZ-Delivery | https://www.az-delivery.de/en/products/drv8825-schrittmotor-treiber-modul-mit-kuhlkorper?variant=37100118866 | €6.99 | 1 | €6.99
 | Servo | Aktor | MG90S | 13.4g, 5V, 22.8x12.2x28.5 | - | AZ-Delivery | https://www.az-delivery.de/en/products/mg90s-micro-servomotor?variant=32344287150176 | €6.99 | 1 | €6.99
 | Lüfter | Aktor | MF25100V11000UA99 | 25x25x10, 8000RPM, 5V | 0.106 | Amazon | https://www.amazon.de/Sunon-MF25100V11000UA99-Fan-0-53-5-9/dp/B07ZBQGCC3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 | €8.53 | 2 | €17.06
B1 | Buchse 4 pin, rechtwinkel. | Buchse | S4B-XH-SM4-TB | Einzel-Kauf, SMT, 2.5mm, 4pin | - | DigiKey | https://www.digikey.de/de/products/detail/jst-sales-america-inc/S4B-XH-SM4-TB/1651064 | €0.78 | 3 | €2.34
B1 | Buchse 3 pin, rechtwinkel. | Buchse | S2B-PH-SM4-TB | Einzel-Kauf, SMT, 2.5mm, 2pin | - | DigiKey | https://www.digikey.de/de/products/detail/jst-sales-america-inc/S2B-PH-SM4-TB/926655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 | €0.53 | 9 | €4.77
B1 | Buchse 2 pin, rechtwinkel. | Buchse | S3B-XH-SM4-TB | Einzel-Kauf, SMT, 2.5mm, 3pin | - | DigiKey | https://www.digikey.de/de/products/detail/jst-sales-america-inc/S3B-XH-SM4-TB/1651065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 | €0.69 | 5 | €3.45
B2 | Buchse rechtwinke. SET | Buchse | - | SET-Kauf, 2mm | - | Amazon | https://www.amazon.de/Stecker-Buchsen-Kabel-Set-kompatibel-JST-PH-Stecker-Dr%C3%A4hte/dp/B0BM82KR17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 | €17.14 | 1 | €17.14
 | Buchse gerade (wird auf Pin-Reihen gesteckt) | Buchse | - | Gerade Buchsen, 2.54mm | - | Amazon | https://www.amazon.de/-/en/YIXISI-Connector-JST-XH-Female-Adapter/dp/B082ZLYRRN | €8.05 | 1 | €8.05
B3 | Pin-Reihen im rechten Winkel | Buchse | - | SET-Kauf, 2,54mm | - | Amazon | https://www.amazon.de/Sourcingmap%C2%AE-rechten-Einreihige-Stiftleiste-PCB-Steckverbinder-Black-Silver-Tone/dp/B01MZE0XGZ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 | €7.55 | 1 | €7.55
B3 | Buchse 4 pin, rechtwinkel. | Buchse | S4B-XH-SM4-TB | Einzel-Kauf, SMT, 2.5mm, 4pin | - | DigiKey | https://www.digikey.de/de/products/detail/jst-sales-america-inc/S4B-XH-SM4-TB/1651064 | €0.78 | 1 | €0.78
 | I2C Bus Extender | Chip | PCA9615DPZ | Macht I2C zu differentiellem I2C | 0.006 | Mouser | https://www.mouser.de/ProductDetail/NXP-Semiconductors/PCA9615DPZ?qs=pBJMDPsKWf3nyRapr7Zy5w%3D%3D | €3.70 | 1 | €3.70
 | 12-Bit I2C ADC | Chip | ADS1015IDGSR | 12-Bit ADC, I2C kompatibel | 0.00015 | DigiKey | https://www.digikey.at/en/products/detail/ADS1015IDGSR/296-41185-1-ND/5222640?curr=eur | €2.50 | 1 | €2.50
 | 4-Bit GPIO | Chip | PCA9536D | vier Ein- oder Ausgänge, die individuell konfiguriert werden können | 3e-05 | DigiKey | https://www.digikey.at/en/products/detail/PCA9536DR/296-21765-1-ND/1629164?curr=eur | €1.39 | 2 | €2.78
SR1 | Spannungsregler | Chip | MIC5219-3.3YM5-TR | Vout: 3v3, 500mA max Ausgangsstrom | - | DigiKey | https://www.digikey.at/en/products/detail/MIC5219-3.3YM5-TR/576-1281-1-ND/771902?curr=eur | €1.11 | 1 | €1.11
SR2 | Spannungsregler | Chip | AP7361C-33ER-13 | 3,3V Ausgangsspannung, 1A max Ausgangsstrom | 3.5e-05 | DigiKey | https://www.digikey.at/en/products/detail/AP7361C-33ER-13/AP7361C-33ER-13DICT-ND/8545922?curr=eur | €0.56 | 1 | €0.56
 | Lüftersteuer (Fan Controller) | Chip | EMC2302-2-AIZL-TR | 3,3V Eingangsspannung, 2 Ausgänge | 0.00025 | DigiKey | https://www.digikey.at/en/products/detail/EMC2302-2-AIZL-TR/EMC2302-2-AIZL-CT-ND/9643014?curr=eur | €1.32 | 1 | €1.32
K1 | Flexibles, verdrilltes, abgeschirmtes Schleppkabel | Kabel | 24AWG | 0.2mm2, 1m, 4 cores | - | Amazon | https://www.amazon.co.uk/Generic-Flexible-Twisted-Shielded-Towline/dp/B0CCJFZHPD?th=1 | €12.02 | 1 | €12.02
K2 | Flexibles, verdrilltes, abgeschirmtes Schleppkabel | Kabel | - | 0.3mm2, 1m, 4 cores | - | ebay | https://www.ebay.at/itm/334182254045 | €3.90 | 1 | €3.90
 | Widerstand | Lagerbestand | - | 120, 330, 600, 1k, 4k7, 10k | - | Amazon | https://www.amazon.de/AUKENIEN-Widerstand-Sortiment-Resistor-Widerst%C3%A4nde/dp/B0B8CV56D7 | €8.66 | 1 | €8.66
 | LED | Lagerbestand | - | Grün, Blau, Gelb | - | Amazon | https://www.amazon.de/-/en/Emitting-Electronic-Components-Assortment-Experience/dp/B0CSDDZJFQ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 | €5.99 | 1 | €5.99
 | Transistor | Lagerbestand | DTC143EKAT146 | Max Ic 100mA, Vmax 50V | - | DigiKey | https://www.digikey.at/en/products/detail/DTC143EKAT146/DTC143EKAT146CT-ND/650721?curr=eur | €0.25 | 4 | €1.00
 | Kapazitäten | Lagerbestand | - | 0.1uF, 0.22uF, 4.7uf | - | Amazon | https://www.amazon.de/-/en/Capacitor-Assortment-Electrolytic-Capacitors-Aluminium/dp/B09QH1RLRS | €18.14 | 1 | €18.14
 | Transistor | Lagerbestand | BSS138 | N-Kanal | - | DigiKey | https://www.digikey.at/en/products/detail/BSS138/BSS138CT-ND/244294?curr=eur | €0.32 | 2 | €0.64
 | Abstandhalter | PCB-Printhead | - | 7mm Abstandhalter | - | DigiKey | https://www.digikey.de/de/products/detail/w%C3%BCrth-elektronik/971070154/9488609 | €0.88 | 10 | €8.80
 | Steckverbinder Female | PCB-Printhead | BF100-16-A-D-1-0640-L-C | 8 Reihenpaare, mit Location Peg | - | DigiKey | https://www.digikey.de/de/products/detail/gct/BF100-16-A-D-1-0640-L-C/16396992 | €0.57 | 4 | €2.28
 | Steckverbinder Male | PCB-Printhead | BF030-16A-B1-0360-0277-0600-LB | 8 Reihenpaare, mit Location Peg | - | DigiKey | https://www.digikey.de/de/products/detail/gct/BF030-16A-B1-0360-0277-0600-LB/16397007 | €0.55 | 4 | €2.20
 | Raspberry Pi Stacking Header | PiShield PCB | Adafruit 2223 | Raspberry Pi Pin row 2x20 | - | DigiKey | https://www.digikey.at/de/products/detail/adafruit-industries-llc/2223/5629433 | €2.30 | 1 | €2.30
TP3 | Temperatur Sensor Coldend | Sensor | B57891M0104J000 | -40/125 C; +-5% | - | DigiKey | https://www.digikey.at/en/products/detail/B57891M0104J000/495-2158-ND/739908?curr=eur | €1.09 | 2 | €2.18
TP2 | Temperatur Sensor Hotend | Sensor | NB-PTCO-182 | -30/300 C; +-0.12% | 0.0004 | DigiKey | https://www.digikey.at/en/products/detail/NB-PTCO-182/223-NB-PTCO-182-ND/13916729?curr=eur | €4.49 | 2 | €8.98
TP1 | Temperatur Sensor Hotend | Sensor | 824-PTFC102B1G0 | -50/600 C; +-0.3C | - | Mouser | https://www.mouser.at/ProductDetail/Measurement-Specialties/PTFC102B1G0 | €2.81 | 4 | €11.24
 | Beschleunigungssensor | Sensor | 1528-1015-ND | I2C, 3 Axis, +-2, 4, 8g | - | DigiKey | https://www.digikey.at/en/products/detail/1231/1528-1015-ND/4990764?curr=eur | €16.10 | 1 | €16.10
DI1 | I2C Bus Extender Breakout Board | Test | Test Breakout Board | https://learn.sparkfun.com/tutorials/qwiic-differential-i2c-bus-extender-pca9615-hookup-guide/all | - | Sparkfun | https://www.sparkfun.com/products/16988 | €11.00 | 1 | €11.00
DI2 | SMD to DIP Adapter SET | Test | SOP8/10/14/16/20/24/28; SOT23/89/223 | Testboard set von amazon | - | Amazon | https://www.amazon.de/-/en/KeeYees-Adapter-Prototype-TQFP100-QQQN444/dp/B085LC6ZSY | €16.13 | 1 | €16.13
DI3 | SMD to DIP One Piece | Test | SOP10 | Einzel-Anschaffung Testboard | - | DigiKey | https://www.digikey.at/en/products/detail/LCQT-MSOP10/A881AR-ND/4754589?curr=eur | €2.97 | 2 | €5.94
DI3 | SMD to DIP One Piece | Test | SOP20 | Einzel-Anschaffung Testboard | - | DigiKey | https://octopart.com/opatz8j6/a1 | €5.92 | 1 | €5.92
DI3 | SMD to DIP One Piece | Test | SOT23 | Einzel-Anschaffung Testboard | - | DigiKey | https://www.digikey.at/en/products/detail/LCQT-SOT23-6/A879AR-ND/4754587?curr=eur | €2.64 | 1 | €2.64
 |  |  |  | Strom-Budget | 0.112465 |  |  | Summe |  | €189.16
 |  |  |  |  |  |  |  | Real-Summe |  | €100.83

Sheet: BOM_DIFi2C_PiShield_20_07
Reference | Value | Datasheet | Footprint | Qty | DNP
A2 | Pololu_Breakout_DRV8825 | https://www.pololu.com/product/2982 | Module:Pololu_Breakout-16_15.2x20.3mm | 1
J1 | DSCL | ~ | 4pin | 1
J2 | DSDA | ~ | - | 1
J3 | Raspberry_Pi_2_3 | https://www.raspberrypi.org/documentation/hardware/raspberrypi/schematics/rpi_SCH_3bplus_1p0_reduced.pdf | Connector_PinSocket_2.54mm:PinSocket_2x20_P2.54mm_Vertical | 1
J4 | 12V_Mainboard | ~ | 2pin | 1
J5 | PWR_Printhead | ~ | 3pin | 1
J9 | ST_CUT_5VLogic | ~ | 3pin | 1
J10 | ST_CUT_Microstepping | ~ | 3pin | 1
J11 | ST_CUT | ~ | 4pin | 1
Q1,Q2 | BSS138 | https://www.onsemi.com/pub/Collateral/BSS138-D.PDF | Package_TO_SOT_SMD:SOT-23 | 2
R1,R2,R3,R4 | 10k | ~ |  | 4
R5,R6 | 4k7 | ~ | Resistor_SMD:R_0402_1005Metric | 2
R7,R9,R10,R12 | 600 | ~ | Resistor_SMD:R_0402_1005Metric | 4
R8,R11 | 120 | ~ | Resistor_SMD:R_0402_1005Metric | 2
U1 | PCA9615DP | https://www.nxp.com/docs/en/data-sheet/PCA9615.pdf | Package_SO:TSSOP-10_3x3mm_P0.5mm | 1

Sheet: BOM_DIFi2C_Printhead_20_07
Reference | Value | Datasheet | Footprint | Qty | DNP
C1,C2,C5,C6,C7,C8,C9,C11 | 0.1ÂµF | ~ | -- mixed values -- | 8
C3,C4 | 0.22ÂµF | ~ | Capacitor_SMD:C_0402_1005Metric | 2
C10 | 0.1ÂµFC | ~ | Capacitor_SMD:C_0402_1005Metric | 1
C12,C13 | 4.7ÂµF | ~ | Capacitor_SMD:C_0402_1005Metric | 2
D1 | GREEN | ~ | LED_SMD:LED_0805_2012Metric | 1
D2 | BLUE | ~ | LED_SMD:LED_0805_2012Metric | 1
D3,D4 | YELLOW | ~ | LED_SMD:LED_0805_2012Metric | 2
H1,H2,H3,H4 | MountingHole_Pad | ~ | MountingHole:MountingHole_2.2mm_M2_Pad_TopBottom | 4
J1 | Power | ~ | Connector_JST:JST_EH_S3B-EH_1x03_P2.50mm_Horizontal | 1
J4 | FAN0 | ~ | Connector_JST:JST_EH_S2B-EH_1x02_P2.50mm_Horizontal | 1
J5 | FAN2 | ~ | Connector_JST:JST_EH_B2B-EH-A_1x02_P2.50mm_Vertical | 1
J7 | FAN3 | ~ | Connector_JST:JST_EH_B2B-EH-A_1x02_P2.50mm_Vertical | 1
J8 | T0 | ~ | Connector_JST:JST_EH_S2B-EH_1x02_P2.50mm_Horizontal | 1
J9 | T1 | ~ | Connector_JST:JST_EH_S2B-EH_1x02_P2.50mm_Horizontal | 1
J10 | T2 | ~ | Connector_JST:JST_EH_B2B-EH-A_1x02_P2.50mm_Vertical | 1
J11 | T3 | ~ | Connector_JST:JST_EH_B2B-EH-A_1x02_P2.50mm_Vertical | 1
J14 | FAN4 | ~ | Connector_JST:JST_EH_B2B-EH-A_1x02_P2.50mm_Vertical | 1
J15 | BreakoutBoardADXL345 | ~ | Connector_JST:JST_EH_B4B-EH-A_1x04_P2.50mm_Vertical | 1
J18 | DATA | ~ | Connector_RJ:RJ45_Molex_0855135013_Vertical | 1
Q1,Q2,Q4,Q5 | DTC143E |  | Package_TO_SOT_SMD:SOT-723 | 4
R1 | 1k | ~ | Resistor_SMD:R_0402_1005Metric | 1
R2,R3,R10,R14,R16,R18,R19,R21,R22 | 4k7 | ~ | Resistor_SMD:R_0402_1005Metric | 9
R4,R6,R7,R9 | 600 | ~ | Resistor_SMD:R_0402_1005Metric | 4
R5,R8 | 120 | ~ | Resistor_SMD:R_0402_1005Metric | 2
R12 | 10k | ~ | Resistor_SMD:R_0402_1005Metric | 1
R20,R25,R26 | 330 | ~ | Resistor_SMD:R_0402_1005Metric | 3
U1 | PCA9615DP | https://www.nxp.com/docs/en/data-sheet/PCA9615.pdf | Package_SO:TSSOP-10_3x3mm_P0.5mm | 1
U2 | EMC2302-2-AIZL-TR | EMC2302-2-AIZL-TR | EMC2302-2-AIZL-TR:MSOP10_MC_MCH | 1
U4 | ADS1015IDGS | http://www.ti.com/lit/ds/symlink/ads1015.pdf | Package_SO:TSSOP-10_3x3mm_P0.5mm | 1
U5 | PCA9536D | http://www.nxp.com/documents/data_sheet/PCA9536.pdf | Package_SO:SOIC-8_3.9x4.9mm_P1.27mm | 1
U6 | AP7361C-33E | https://www.diodes.com/assets/Datasheets/AP7361C.pdf | Package_TO_SOT_SMD:SOT-223-3_TabPin2 | 1

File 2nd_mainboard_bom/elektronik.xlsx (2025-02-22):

Alternative | Bezeichnung | Kategorie | Seriennummer | Beschreibung | Lieferant | URL | Preis/Stk. | Stückzahl | Gesamtpreis | Gesamt-Real-Sum | €64.30 | Gesamt-Sum | €359.47
 | Schrittmotor | Aktor | 14HM08-0504S | Bipolar, 5Ncm, 35x35x20, 90g | Stepperonline | https://www.omc-stepperonline.com/de/nema-14-bipolar-0-9deg-5ncm-7-08oz-in-0-5a-5v-35x35x20mm-4-draehte-14hm08-0504s | €9.91 | 1 | €9.91 | BP2, BF4, SP2, F2, S1, ACC3, TP2
S1 | Schrittmotor-Treiber | Aktor | DRV8825 | Bipolarer SM, full step to 1/32 step | AZ-Delivery | https://www.az-delivery.de/en/products/drv8825-schrittmotor-treiber-modul-mit-kuhlkorper?variant=37100118866 | €6.99 | 1 | €6.99
S2 | Schrittmotor-Treiber | Aktor | TMC2009 | Bipol | 3D-Jake | https://www.3djake.at/bigtreetech/stepper-motor-driver | €6.99 | 1 | €6.99
 | Servo | Aktor | MG90S | 13.4g, 5V, 22.8x12.2x28.5 | AZ-Delivery | https://www.az-delivery.de/en/products/mg90s-micro-servomotor?variant=32344287150176 | €6.99 | 1 | €6.99 | Summe | €180.72
F1 | Lüfter | Aktor | MF25100V11000UA99 | 25x25x10, 13000RPM | Amazon | https://www.amazon.de/Sunon-MF25100V11000UA99-Fan-0-53-5-9/dp/B07ZBQGCC3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 | €8.53 | 4 | €34.12 | Real-Summe | €30.18
F2 | Lüfter | Aktor | CFM-2507CF-1140-313 | 25x25x7, 14000PRM | DigiKey | https://www.digikey.at/en/products/detail/same-sky-formerly-cui-devices/CFM-2507CF-1140-313/19524850 | €6.73 | 2 | €13.46
F2 | Lüfter | Aktor | CFM-2507CF-0140-313 | 25x25x7, 14000PRM | DigiKey | https://www.digikey.at/en/products/detail/same-sky-formerly-cui-devices/CFM-2507CF-0140-313/19524735 | €7.40 | 2 | €14.80
BF1 | Buchse 4 pin, rechtwinkel. | Buchse | S4B-XH-SM4-TB | Einzel-Kauf, SMD, 2.5mm, 4pin, 3A | DigiKey | https://www.digikey.de/de/products/detail/jst-sales-america-inc/S4B-XH-SM4-TB/1651064 | €0.69 | 3 | €2.07
BF1 | Buchse 2 pin, rechtwinkel. | Buchse | S2B-PH-SM4-TB | Einzel-Kauf, SMD, 2.5mm, 2pin | DigiKey | https://www.digikey.de/de/products/detail/jst-sales-america-inc/S2B-PH-SM4-TB/926655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 | €0.53 | 9 | €4.77
BF1 | Buchse 3 pin, rechtwinkel. | Buchse | S3B-XH-SM4-TB | Einzel-Kauf, SMD, 2.5mm, 3pin | DigiKey | https://www.digikey.de/de/products/detail/jst-sales-america-inc/S3B-XH-SM4-TB/1651065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 | €0.69 | 5 | €3.45
BF2 | Buchse rechtwinke. SET | Buchse | - | SET-Kauf, 2mm | Amazon | https://www.amazon.de/Stecker-Buchsen-Kabel-Set-kompatibel-JST-PH-Stecker-Dr%C3%A4hte/dp/B0BM82KR17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 | €17.14 | 1 | €17.14
BF2.1 | Buchse gerade (wird auf Pin-Reihen gesteckt) | Buchse | - | Gerade Buchsen, 2.54mm | Amazon | https://www.amazon.de/-/en/YIXISI-Connector-JST-XH-Female-Adapter/dp/B082ZLYRRN | €8.05 | 1 | €8.05
BF3 | Pin-Reihen im rechten Winkel | Buchse | - | SET-Kauf, 2,54mm | Amazon | https://www.amazon.de/Sourcingmap%C2%AE-rechten-Einreihige-Stiftleiste-PCB-Steckverbinder-Black-Silver-Tone/dp/B01MZE0XGZ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 | €7.55 | 1 | €7.55
BF4 | Buchse 4 pin, rechtwinkel. | Buchse | S4B-XH-A-1 | Einzel-Kauf, THT, 2.5mm, 4pin, 3A | DigiKey | https://www.digikey.at/en/products/detail/jst-sales-america-inc/S4B-XH-A-1/9961923 | €0.22 | 1 | €0.22
BF4 | Buchse 2 pin, rechtwinkel. | Buchse | S3B-XH-A-1 | Einzel-Kauf, THT, 2.5mm, 3pin | DigiKey | https://www.digikey.at/en/products/detail/jst-sales-america-inc/S3B-XH-A-1/1556255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 | €0.18 | 2 | €0.36
BF4 | Buchse 3 pin, rechtwinkel. | Buchse | S2B-XH-A-1 | Einzel-Kauf, THT, 2.5mm, 2pin | DigiKey | https://www.digikey.at/en/products/detail/jst-sales-america-inc/S2B-XH-A-1/9961922 | €0.14 | 8 | €1.12
 | USB-C Stecker | Buchse | USB4085-GF-A | USB 2.0, Shielded | DigiKey | https://www.digikey.at/en/products/detail/gct/USB4085-GF-A/9859662 | €0.84 | 1 | €0.84
BP1 | Leistungseingang-Buchse | Buchse | JACK-L-PC-10A-RA(R) | 10A, 2 Pole, 2,5mmx5,5mm, 50VDC | DigiKey | https://www.digikey.de/en/products/detail/globtek-inc/JACK-L-PC-10A-RA-R/8597890 | €3.24 | 1 | €3.24
BP2 | Leistungseingang-Buchse | Buchse | PJ-082BH | 10A, 2 Pole, 2,5mmx5,5mm, 36VDC | DigiKey | https://www.digikey.de/en/products/detail/same-sky-formerly-cui-devices/PJ-082BH/3477156 | €1.70 | 1 | €1.70
SP1 | Leistungskabel-Stecker | Stecker | 50-00542 | 10A, 2 Pole, 2,5mmx5,5mm, 48VDC | DigiKey | https://www.digikey.at/en/products/detail/tensility-international-corp/50-00542/7087237 | €0.82 | 1 | €0.82
SP2 | Leistungskabel-Stecker | Stecker | 50-00619 | 8V, 2 Pole, 2,5mmx5,5mm, 48VDC | DigiKey | https://www.digikey.at/en/products/detail/tensility-international-corp/50-00619/10261135 | €0.94 | 1 | €0.94
SP3 | Leistungskabel-Stecker | Stecker | PP3-002B | 7A, 2 Pole, 2,5mmx5,5mm, 24VDC | DigiKey | https://www.digikey.at/en/products/detail/same-sky-formerly-cui-devices/PP3-002B/992137 | €1.33 | 1 | €1.33
 | Leistungskabel | Kabel | 44A0221-16-9/9CS3030 | 16 AWG | DigiKey | https://www.digikey.de/en/products/detail/te-connectivity-aerospace-defense-and-marine/44A0221-16-9-9CS3030/6058883 | €2.04 | 1 | €2.04
 | Kabelstecker-Gehäuse | Kabel | XHP-2 | 2 Pole | DigiKey | https://www.digikey.at/de/products/detail/jst-sales-america-inc/XHP-2/555485 | €0.10 | 10 | €1.00
CK1 | Crimpkontakte für den Kabelstecker | Kabel | SXH-001T-P0.6N | 100 Stück, 22-26 AWG | DigiKey | https://www.digikey.at/de/products/detail/jst-sales-america-inc/SXH-001T-P0-6N/7041446 | €5.54 | 1 | €5.54
 | Widerstand | Lagerbestand | - | 120, 330, 600, 1k, 4k7, 10k | Amazon | https://www.amazon.de/AUKENIEN-Widerstand-Sortiment-Resistor-Widerst%C3%A4nde/dp/B0B8CV56D7 | €8.66 | 1 | €8.66
 | LED | Lagerbestand | - | Grün, Blau, Gelb | Amazon | https://www.amazon.de/-/en/Emitting-Electronic-Components-Assortment-Experience/dp/B0CSDDZJFQ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 | €5.99 | 1 | €5.99
 | Kapazitäten | Lagerbestand | - | 0.1uF, 0.22uF, 4.7uf | Amazon | https://www.amazon.de/-/en/Capacitor-Assortment-Electrolytic-Capacitors-Aluminium/dp/B09QH1RLRS | €18.14 | 1 | €18.14
 | N-MOSFET als Fan-Ansteuerung | Bestellbestand | RJK0456DPB-00#J5 | 40V, 50A Ta, Vgsmax +-20V | DigiKey | https://www.digikey.de/en/products/detail/renesas-electronics-corporation/RJK0456DPB-00-J5/2694914 | €2.91 | 2 | €5.82
 | Quarz-Oszillator für Microchip | Bestellbestand | ECS-160-18-4X-CKM | 16 MHz 18pF, +-10ppm | DigiKey | https://www.digikey.at/de/products/detail/ecs-inc/ECS-160-18-4X-CKM/12349451 | €0.41 | 1 | €0.41
 | Reset-Button | Bestellbestand | PTS647SM38SMTR2 LFS | 4.5x4.5x3.8mm, SMD | DigiKey | https://www.digikey.at/en/products/detail/c-k/PTS647SM38SMTR2-LFS/9649861 | €0.23 | 1 | €0.23
 | P-MOSFET als Verpolungsschutz | Schutzschlatung | SQJ409EP-T1_GE3 | 40V, max 60A Tc, max 68W Tc | DigiKey | https://www.digikey.at/de/products/detail/vishay-siliconix/SQJ409EP-T1-GE3/7326286 | €1.56 | 1 | €1.56
 | Zener Diode | Schutzschlatung | SZ1SMB5927BT3G | 12V, 3W | DigiKey | https://www.digikey.de/en/products/detail/onsemi/SZ1SMB5927BT3G/9960092 | €0.47 | 1 | €0.47
 | TSV Diode | Schutzschlatung | 824521241 | 15,5 A max | Digikey | https://www.digikey.de/en/products/detail/w%C3%BCrth-elektronik/824521241/5870552 | €0.30 | 1 | €0.30
 | 12-40V zu 40V Buck | Chip | LM2679SX-12/NOPB | Ausgangsstrom 5A, 260kHz, 12V fixed | DigiKey | https://www.digikey.at/en/products/detail/texas-instruments/LM2679SX-12-NOPB/366925 | €5.79 | 1 | €5.79
 | 12V zu 5V Buck | Chip | LM22676MRX-5.0/NOPB | Ausgangsstrom 3A, 500kHz, 5V fixed | DigiKey | https://www.digikey.at/en/products/detail/texas-instruments/LM22676MRX-5-0-NOPB/1951965 | €4.14 | 1 | €4.14
 | Microchip | Chip | ATMEGA328P-AU | 8-Bit, 20MHz, AVR | DigiKey | https://www.digikey.de/en/products/detail/microchip-technology/ATMEGA328P-AU/1832260 | €2.55 | 1 | €2.55
 | USB-Serial Wandler | Chip | FT232RNL-TUBE | USB 2.0, 3V3 OUT | DigiKey | https://www.digikey.at/en/products/detail/ftdi-future-technology-devices-international-ltd/FT232RNL-TUBE/16836164 | €4.60 | 1 | €4.60
 | Fan-Controller mit Richtungswechsel | Chip | TPM16050-S6TR | 500mA, 2,9-17V, | DigiKey | https://www.digikey.at/en/products/detail/3peak/TPM16050-S6TR/22229143 | €0.60 | 1 | €0.60
 | Abstandhalter | PCB-Printhead | - | 7mm Abstandhalter | DigiKey | https://www.digikey.de/de/products/detail/w%C3%BCrth-elektronik/971070154/9488609 | €0.88 | 10 | €8.80
 | Steckverbinder Female | PCB-Printhead | BF100-16-A-D-1-0640-L-C | 8 Reihenpaare, mit Location Peg | DigiKey | https://www.digikey.de/de/products/detail/gct/BF100-16-A-D-1-0640-L-C/16396992 | €0.57 | 4 | €2.28
 | Steckverbinder Male | PCB-Printhead | BF030-16A-B1-0360-0277-0600-LB | 8 Reihenpaare, mit Location Peg | DigiKey | https://www.digikey.de/de/products/detail/gct/BF030-16A-B1-0360-0277-0600-LB/16397007 | €0.55 | 4 | €2.20
TP3 | Temperatur Sensor Coldend | Sensor | B57891M0104J000 | -40/125 C; +-5% | DigiKey | https://www.digikey.at/en/products/detail/B57891M0104J000/495-2158-ND/739908?curr=eur | €1.09 | 2 | €2.18
TP2 | Temperatur Sensor Hotend | Sensor | NB-PTCO-182 | -30/300 C; +-0.12% | DigiKey | https://www.digikey.at/en/products/detail/NB-PTCO-182/223-NB-PTCO-182-ND/13916729?curr=eur | €4.49 | 2 | €8.98
TP1 | Temperatur Sensor Hotend | Sensor | 824-PTFC102B1G0 | -50/600 C; +-0.3C | Mouser | https://www.mouser.at/ProductDetail/Measurement-Specialties/PTFC102B1G0 | €2.81 | 4 | €11.24
TP2 | Temperatur Sensor Hotend | Sensor | Hotend Thermistor, Ender 3 S1 | 100 kΩ bei 25 °C | 3D-Jake | https://www.3djake.com/creality-3d-printers-spare-parts/hotend-thermistor | €5.99 | 4 | €23.96
TP3 | Temperatur Sensor Hotend | Sensor | 100k Ohm NTC Thermistor - Semitec |  | 3D-Jake | https://www.3djake.com/e3d/100k-ohm-ntc-thermistor-semitec | €2.99 | 4 | €11.96
TP3 | Kabelstecker-Gehäuse | Sensor | XHP-2 | 2 Pole | DigiKey | https://www.digikey.at/de/products/detail/jst-sales-america-inc/XHP-2/555485 | €0.10 | 10 | €1.00
TP3 | Crimpkontakte für den Kabelstecker | Sensor | SXH-001T-P0.6N | 100 Stück, 22-26 AWG | DigiKey | https://www.digikey.at/de/products/detail/jst-sales-america-inc/SXH-001T-P0-6N/7041446 | €5.54 | 1 | €5.54
TP4 | SMD Temperatursensor | Sensor | ABNTC-0805-103J-3950F-T | 3950K, 200mW, -55 bis 125°C | DigiKey | https://www.digikey.at/de/products/detail/abracon-llc/ABNTC-0805-103J-3950F-T/4245607 | €0.19 | 1 | €0.19
ACC1 | Beschleunigungssensor | Sensor | 1528-1015-ND | I2C, 3 Axis, +-2, 4, 8g | DigiKey | https://www.digikey.at/en/products/detail/1231/1528-1015-ND/4990764?curr=eur | €16.10 | 1 | €16.10
ACC2 | Beschleunigungssensor | Sensor | ADXL345 | I2C, 3 Axis, +-2, 4, 8g | Amayon | https://www.amazon.com/-/de/dp/B0BHP8CKDT | €6.99 | 1 | €6.99
ACC3 | Beschleunigungssensor | Sensor | Sunfounder GY-521 MPU-6050 | I2C, 3 Axis, +-2, 4, 8, 16g | RobotShop | https://eu.robotshop.com/products/sunfounder-gy-521-mpu-6050-6-dof-gyro-accelerometer-imu | €9.33 | 1 | €9.33
ACC4 | Beschleunigungssensor | Sensor | BHI160B | SMD-Chip | DigiKey | https://www.digikey.de/de/products/detail/bosch-sensortec/BHI160B/9674248 | €3.39 | 1 | €3.39
DI2 | SMD to DIP Adapter SET | Test | SOP8/10/14/16/20/24/28; SOT23/89/223 | Testboard set von amazon | Amazon | https://www.amazon.de/-/en/KeeYees-Adapter-Prototype-TQFP100-QQQN444/dp/B085LC6ZSY | €16.13 | 1 | €16.13
DI3 | SMD to DIP One Piece | Test | SOP10 | Einzel-Anschaffung Testboard | DigiKey | https://www.digikey.at/en/products/detail/LCQT-MSOP10/A881AR-ND/4754589?curr=eur | €2.97 | 2 | €5.94
DI3 | SMD to DIP One Piece | Test | SOP20 | Einzel-Anschaffung Testboard | DigiKey | https://octopart.com/opatz8j6/a1 | €5.92 | 1 | €5.92
DI3 | SMD to DIP One Piece | Test | SOT23 | Einzel-Anschaffung Testboard | DigiKey | https://www.digikey.at/en/products/detail/LCQT-SOT23-6/A879AR-ND/4754587?curr=eur | €2.64 | 1 | €2.64

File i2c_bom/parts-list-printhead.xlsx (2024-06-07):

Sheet: BOM
Projekt: | Klatschschalter |  |  |  |  |  |  |  |  |  | Gruppe: |  |  |  |  |  | Schuljahr: |  |  |  |  |  | Schuljahr:
Name lt. Schaltplan: | Wert: | Beschreibung: | Toleranz: | Gehäuse: | Hersteller: | Herstellernummer: | Stückzahl lt. Schaltplan: | Notiz | Ausgewählte Stückzahl: | Ausgwählter Preis: | RS |  |  |  |  |  | Digi-Key |  |  |  |  |  | Alternativer Lieferant
 |  |  |  |  |  |  |  |  |  |  | Artikelnummer: | Link: | Verpackungseinheit: | Preis pro Stk.: | Preis gesamt: | Lieferzeit: | Artikelnummer: | Link: | Verpackungseinheit: | Preis pro Stk.: | Preis gesamt: | Lieferzeit: | Lieferant: | Artikelnummer: | Link: | Verpackungseinheit: | Preis pro Stk.: | Preis gesamt: | Lieferzeit:
RV1 | 10K | Piher PT10LV10-103A2020-PM-S Trimmer linear 0.15 W 10 kΩ 220 ° 240 ° 1 St. | +/- 20% | THT, RM 5mm,10mm | Piher | PT10LV10-103A2020-PM-S | 1
J1, J2, J3, J4, J5, J6, J7 | Male Connector | Amphenol Communications Solutions BergStik Stiftleiste gerade, 36-polig / 1-reihig, Raster 2.54mm, Platine-Platine, |  | THT 2,54 | Amphenol | 77311-401-36LF | 1
Arduino Uno | Arduino UNO R3 (ATMEGA328 in SMD) | Arduino UNO R3 (ATMEGA328 in SMD)mit Kabel, Mikrocontroller Board AZ-ATmega328-Board mit USB-Kabel |  |  | AZ-Delivery |  | 1
Netzteil für Arduino Uno | 12W, 100V ac, 9V dc / 1.28A | XP Power VEL12 Steckernetzteil AC/DC-Adapter 12W, 100V ac, 9V dc / 1.28A, EU-Netzstecker |  |  | XP Power (https://at.rs-online.com/web/b/xp-power/) | VEL12US090-EU-JA | 1
LDR |  | LDR Luna Optoelectronics |  |  | Luna Optoelectronics (https://at.rs-online.com/web/b/luna-optoelectronics/) | NSL-19M51 | 1
PMMA Gehäuse | PMMA schwarz 3mm | PMMA schwarz 3mm 3050x2030mm |  | 3Stk. 3050x2030 mit €38.-/m² excl | ThyssenKrupp AG |  | 0.3
Nylon Distanhzhülsen | Ø 3.6mm x 7mm, Länge 5mm | Fischer Elektronik Nylon Distanzhülse, Ø 3.6mm x 7mm, Länge 5mm |  |  | Fischer Elektronik (https://at.rs-online.com/web/b/fischer-elektronik/) | DR 75 V0 | 3
Senkkopfschraube | M3 x 10mm | RS PRO Senkkopf Pozidriv Schrauben verzinkt, M3 x 10mm Stahl |  | M3 | RS Pro | 908-7485 | 8
Abstandhalter | M3x40 | RS PRO Abstandshalter: M3 x M3, Länge 40mm, Messing, Innen/Innen, Sechskant M3 M3, 5.5mm 6mm |  | M3 | RS Pro | 224-0378 | 4
Sechkantmutter | M3x40 | RS PRO Sechskantmuttern, M3 Stahl 5.5mm Glanzverzinkt DIN 934 |  | M3 | rs components über bbg | 560-293 | 3
Drucktaster | 15 A, 250 V ac | Bulgin 8300 Drucktaster Rastend Tafelmontage, Wechselschalter, 2-polig / 15 A @ 250 V ac |  |  | Arcolectric (Bulgin) Ltd (https://at.rs-online.com/web/b/arcolectric--bulgin--ltd/) | H8350ABAAAB | 1
LED-Streifen |  | WS2812B LED Streifen Strip 5M WS2812 RGB Leiste Licht 5050 SMD Adressierbar DC5V, 5m 300LED´s, IP65 | - |  | ebay |  | 2.5
Mikrofon | 4.5 - 10 V/DC Frequenz-Bereich=100 Hz - 10000 Hz | TRU COMPONENTS TC-9202044 Mikrofon-Kapsel 4.5 - 10 V/DC Frequenz-Bereich=100 Hz - 10000 Hz |  | THT | TRU COMPONENTS | TC-9202044 | 1
Leiterplatte kupferkaschiert FR4 | Kupfer 35μm, 1-seitig, 100 x 160 x 1.6mm | Bungard 120306E33-10 Basismaterial einseitig 35 µm Fotobeschichtung positiv (L x B) 160 mm x 100 mm 10 St. |  |  | Bungard | 120306E33-10 | 0.33
Belichtungsfolie Transparent | Laserfolie A4 | AVERY Zweckform Overhead Folien 100 Stk. für S/W Kopierer 3555 A4 transparent |  |  | Fortex |  | 1
Kaltzinn
Isolier- und Schutzlack | Isolier- und Schutzlack 400 ml |  |  |  | Kontakt Chemie | 74313-AA | 0.1
Entwickler | Natriumhydroxid Entwickler |  |  |  | Proma | 150 002c | 0.1
Ätzmittel | Natriumpersulfag 2,5kg |  |  |  | Carl Roth | 4365.3 | 0.1
Kosten Gesamt: | €0.0

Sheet: Spezifikationen Bauelemente
Projekt: | Klatschschalter
Bauelement: | Material: | Toleranz: | Leistung/Spannung: | Gehäuse_KiCad:
Widerstand | Metallschicht | +/-1% | 0,25W | Resistor_THT:R_Axial_DIN0207_L6.3mm_D2.5mm_P10.16mm_Horizontal
Widerstand veränderbar | Trimmer | +/-20% | 0,10W | Potentiometer_THT:Potentiometer_Piher_PT-10-V10_Vertical_Hole
Kondensator | Elektrolyt | +/-20% | 50V | Capacitor_THT:CP_Radial_D5.0mm_P2.50mm
Kondensator | Folie | +/-5% | 63V | Capacitor_THT:C_Disc_D7.0mm_W2.5mm_P5.00mm
J1, J2, J3, J4, J5, J6, J7 |  |  | Stiftleiste für Durchsteckmontage, 1-reihig, Raster 2..54mm | Connector_PinHeader_2.54mm:PinHeader_1x02_P2.54mm_Vertical
Transistoren |  |  |  | Package_TO_SOT_THT:TO-92L_Inline_Wide
Leiterplatte kupferkaschiert FR4 |  | Kupfer 35μm, 1-seitig, 100 x 160 x 1.6mm | Fortex 1.6mm Leiterplatte kupferkaschiert FR4, Kupfer 35μm, 1-seitig, 100 x 160 x 1.6mm
Batteriekontakt |  | 9 V PP3-Batterien, 1-zellig Messing Druckknopf
Belichtungsfolie Transparent |  | Laserfolie A4
9V Alkali Batterie Block |  | 9V Alkali Block
Lötzinn |  | CHIPQUIK SMD LTLF Lötpaste bleifrei, Spritze 15g
Kaltzinn
Flussmittelentferner |  | FLU Flussmittelentferner für Leiterplatten, Spray 400 ml
Isolier- und Schutzlack |  | Isolier- und Schutzlack 400 ml
Entwickler
Ätzmittel |  | Natriumpersulfag 2,5kg

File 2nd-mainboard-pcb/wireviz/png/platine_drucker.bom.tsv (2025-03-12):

Id | Description | Qty | Unit | Designators | Manufacturer | MPN | Supplier | SPN
1 | Cable, 2 x 1.5 mm² shielded, BK | 2 | m | CF881-15-02 | Igus | CF881-15-02
2 | Connector, 3D-Drucker-Netzteil, 3 pins | 1 |  | J2
3 | Connector, Leistungseingang, 6 pins | 1 |  | J1 | Same Sky | PJ-082BH | Digikey | 3477156

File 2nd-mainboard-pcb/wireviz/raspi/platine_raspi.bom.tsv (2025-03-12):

Id | Description | Qty | Unit | Designators | Manufacturer | MPN | Supplier | SPN
1 | Cable, 4 x 28 AWG shielded, BK | 1 | m | USB_Cable | Generic | USB_CABLE_XYZ
2 | Connector, USB-A Buchse, USB2.0, 5 pins | 1 |  | Raspberry_Pi
3 | Connector, USB-C Buchse, USB2.0, 17 pins | 1 |  | P1 | GCT | USB4085-GF-A | Digikey | 9859662

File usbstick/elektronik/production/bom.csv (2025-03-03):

Designator | Footprint | Quantity | Value | LCSC Part #
A1 | drv8825 | 1 | DRV8825
C1, C10, C13, C16, C17, C20, C23, C26, C27, C29, C35, C37, C38, C6, C7 | 0402 | 15 | 100nF
C11, C12, C15, C24, C3, C34, C36, C4 | 0805 | 8 | 10µF
C14 | 1210 | 1 | 22µF
C18 | 0805 | 1 | 1uF
C19, C25, C28 | 0805 | 3 | 4.7uF
C2, C9 | 1210 | 2 | 22nF
C21, C22 | 0402 | 2 | 18pF
C30, C31, C32, C33 | 0402 | 4 | 0.1µF
C5 | 1210 | 1 | 10µF
C8 | 1210 | 1 | 47µF
D1, D2 | 824521241 | 2 | WE-TVSP_DO-214AA_600W_BI
D3, D4, D5, D6 | 0805 | 4 | YELLOW
D7 | 0805 | 1 | GREEN
H1, H2, H3, H4 | MountingHole_2.7mm_M2.5_ISO7380_Pad_TopBottom_7mm | 4 | MountHole
H10, H11, H12, H9 | MountingHole_2.7mm_M2.5_ISO7380_Pad_TopBottom | 4 | MountHole
H5, H6, H7, H8 | MountingHole_2.7mm_M2.5_ISO7380_Pad_TopBottom_111mm | 4 | MountHole
J1 | CUI_PJ-082BH | 1 | PJ-082BH
J10 | JST_XH_S3B-XH-A_1x03_P2.50mm_Horizontal | 1 | BL Touch
J11, J22 | 665102131822 | 2 | T3
J12 | SAMTEC_TSM-107-04-L-DV | 1 | Steckverbinder_Male_Fans
J13 | SAMTEC_HLE-107-02-L-DV | 1 | Steckverbinder_Female_Leistung
J14 | CONN_S2B-XH-A-1LFSN_JST | 1 | FAN3
J15 | SAMTEC_HLE-107-02-L-DV | 1 | Steckverbinder_Female_Motoren
J16 | PinHeader_2x03_P2.54mm_Vertical | 1 | ISP
J18 | PinSocket_1x02_P2.54mm_Vertical | 1 | Quartz
J19, J20, J21 | 665102131822 | 3 | T2
J2, J3 | FTS_103_01_F_S | 2 | Fan_12/5V_Regelung
J23 | PinSocket_1x04_P2.54mm_Vertical | 1 | Conn_01x04_Socket
J24 | SAMTEC_HW-07-08-L-D-250-SM | 1 | Steckverbinder_Male_Leistung
J4 | CONN_S2B-XH-A-1LFSN_JST | 1 | FAN0
J5 | CONN_S2B-XH-A-1LFSN_JST | 1 | FAN1
J6 | CONN_S2B-XH-A-1LFSN_JST | 1 | FAN2
J7 | JST_S4B-XH-A-1 | 1 | Stepper
J8 | JST_XH_S3B-XH-A_1x03_P2.50mm_Horizontal | 1 | Scheindm.
J9 | FTSH-103-01-L-DH | 1 | Microstepping
L1 | SPM10040T_4R7M_HZ | 1 | 4.7µH
L2 | IHLP2525CZER3R3M11 | 1 | 3.3µH
P1 | USB_C_Receptacle_GCT_USB4085 | 1 | USB_C_Receptacle_USB2.0_14P
R1 | 0402 | 1 | 100k
R10, R9 | 0402 | 2 | 5k1
R11, R17, R8 | 0402 | 3 | 10k
R12, R13, R14, R15 | 0402 | 4 | 330
R16 | 0402 | 1 | 1k
R2 | 0603 | 1 | 100k
R22, R23, R24, R25 | 0402 | 4 | 4k7
R3 | 0402 | 1 | 30k
R4 | 0402 | 1 | 1k58
R5 | 0402 | 1 | 30.1k
R6 | 0402 | 1 | 10
R7 | 0402 | 1 | 54.9k
TP18 | TestPoint_Pad_D2.0mm | 1 | ADC2
TP19 | TestPoint_Pad_D2.0mm | 1 | ADC3
TP2 | TestPoint_Pad_D3.0mm | 1 | GND_Test
TP20 | TestPoint_Pad_D2.0mm | 1 | ADC1
TP21 | TestPoint_Pad_D2.0mm | 1 | ADC0
TP22 | TestPoint_2Pads_Pitch2.54mm_Drill0.8mm | 1 | I_Sense_5VUSBC
TP23 | TestPoint_2Pads_Pitch2.54mm_Drill0.8mm | 1 | I_Sense_5VPOW
TP25 | TestPoint_2Pads_Pitch2.54mm_Drill0.8mm | 1 | I_Sense_12V
TP3 | TestPoint_Pad_D3.0mm | 1 | 12V_Test
TP6 | TestPoint_Pad_D3.0mm | 1 | 5V_USBC_Test
TP7 | TestPoint_Pad_D3.0mm | 1 | 5V_POW_Test
TP8 | TestPoint_Loop_D3.80mm_Drill2.5mm | 1 | Quartz_1
TP9 | TestPoint_Loop_D3.80mm_Drill2.5mm | 1 | Quartz_2
U1 | SQJ409EP_T1_GE3 | 1 | SQJ409EP-T1_GE3
U10 | TQFP-32_7x7mm_P0.8mm | 1 | ATmega328PB-A
U12 | InvenSense_QFN-24_4x4mm_P0.5mm | 1 | MPU-6050
U2 | SZ1SMB5927BT3G | 1 | SZ1SMB5927BT3G
U3 | TPS56837HRPAR | 1 | TPS56837HRPAR
U4 | SOT-23-6 | 1 | TPS565208
U5 | SSOP-28_5.3x10.2mm_P0.65mm | 1 | FT232RL
U6 | SW_PTS647SM38SMTR2LFS_CNK | 1 | PTS647SM38SMTR2LFS
U7 | TPM16050_S6TR | 1 | TPM16050-S6TR
U8, U9 | RJK0456DPB_00_J5 | 2 | RJK0456DPB
Y1 | XTAL_ECS-160-18-4X-CKM | 1 | ECS-160

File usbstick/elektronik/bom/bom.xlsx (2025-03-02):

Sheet: 2ndMainBoard
Alternative | Bezeichnung | Seriennummer |  |  | Kauf | Stückzahl | Gesamtpreis | Gesamt-Real-Sum | €19.07
 | Raspberry Pi | Raspberry Pi 3B+ |  |  | DigikKey | 1 | €33.37
 | Microchip | ATMEGA328P-AU |  |  | DigiKey | 1 | €2.55
 | USB-Serial Wandler | FT232RNL-TUBE |  |  | DigiKey | 1 | €4.60
 | Quarz-Oszillator für Microchip | ECS-160-18-4X-CKM |  | https://www.digikey.at/de/products/detail/ecs-inc/ECS-160-18-4X-CKM/12349451 | DigiKey | 1 | €0.41
 | Reset-Button | PTS647SM38SMTR2 LFS |  |  | DigiKey | 1 | €0.23
 | Schrittmotor | 14HM08-0504S |  | https://www.omc-stepperonline.com/de/nema-14-bipolar-0-9deg-5ncm-7-08oz-in-0-5a-5v-35x35x20mm-4-draehte-14hm08-0504s | Stepperonline | 1 | €9.91 | Summe | €221.25
S1 | Schrittmotor-Treiber | DRV8825 |  | https://www.az-delivery.de/en/products/drv8825-schrittmotor-treiber-modul-mit-kuhlkorper?variant=37100118866 | AZ-Delivery | 1 | €6.99
S2 | Schrittmotor-Treiber | TMC2009 |  |  | 3D-Jake | 1 | €6.99 | Real-Summe | €14.03
 | Servo | MG90S |  | https://www.az-delivery.de/en/products/mg90s-micro-servomotor?variant=32344287150176 | AZ-Delivery | 1 | €6.99
BL | Nivellierungssensor | BLTouch Nivellierungssensor |  |  | 3D-Jake | 1 | €39.99
ACC1 | Beschleunigungssensor | 1528-1015-ND |  | https://www.digikey.at/en/products/detail/1231/1528-1015-ND/4990764?curr=eur | DigiKey | 1 | €16.10
ACC2 | Beschleunigungssensor | ADXL345 |  |  | Amazon | 1 | €6.99
ACC3 | Beschleunigungssensor | Sunfounder GY-521 MPU-6050 |  |  | AZ-Delivery | 1 | €5.99
ACC4 | Beschleunigungssensor | BHI160B |  |  | DigiKey | 1 | €3.39
F1 | Lüfter | MF25100V11000UA99 |  | https://www.amazon.de/Sunon-MF25100V11000UA99-Fan-0-53-5-9/dp/B07ZBQGCC3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 | Amazon | 4 | €34.12
F2 | Lüfter | CFM-2507CF-1140-313 |  | https://www.digikey.at/en/products/detail/same-sky-formerly-cui-devices/CFM-2507CF-1140-313/19524850 | DigiKey | 2 | €13.46
F2 | Lüfter | CFM-2507CF-0140-313 |  | https://www.digikey.at/en/products/detail/same-sky-formerly-cui-devices/CFM-2507CF-0140-313/19524735 | DigiKey | 2 | €14.80
 | Temperaturelement | B57550G1103F005 |  |  | DigiKey | 4 | €10.00
ST_TEMP | 2 Pin Stecker f. Temperatursensor | 665002113322 |  |  | DigiKey | 4 | €0.52
ST_TEMP | 2 Pin Buchse f. Temperatursensor | 665102131822 |  |  | DigiKey | 4 | €2.44
TP_SMD | SMD Temperatursensor | ABNTC-0805-103J-3950F-T |  |  | DigiKey | 2 | €0.38
POW1 | 12-40V zu 40V Buck | LM2679SX-12/NOPB |  |  | DigiKey | 1 | €5.79
POW1 | 12V zu 5V Buck | LM22676MRX-5.0/NOPB |  |  | DigiKey | 1 | €4.14
POW2 | 12-40V zu 40V Buck | TPS56837HRPAR |  |  | DigiKey | 1 | €2.34
POW2 | 12V zu 5V Buck | TPS565208DDCR |  |  | DigiKey | 1 | €1.17
 | Spule 12V Buck | SPM10040T-4R7M-HZ |  |  | DigiKey | 1 | €1.78
 | Spule 5V Buck | IHLP2525CZER3R3M11 |  |  | DigiKey | 1 | €0.95
 | P-MOSFET als Verpolungsschutz | SQJ409EP-T1_GE3 |  |  | DigiKey | 1 | €1.56
 | Zener Diode | SZ1SMB5927BT3G |  |  | DigiKey | 1 | €0.47
 | TSV Diode | 824521241 |  |  | Digikey | 2 | €0.60
OP | Ferritperle | MPZ1005S331ET000 |  |  | DigiKey | 1 | €0.30
 | N-MOSFET als Fan-Ansteuerung | RJK0456DPB-00#J5 |  |  | DigiKey | 2 | €5.82
 | Fan-Controller mit Richtungswechsel | TPM16050-S6TR |  |  | DigiKey | 1 | €0.60
 | USB-C Kabel | A-USB31C-20A-150A |  |  | DigiKey | 1 | €9.25
 | USB-C Buchse | USB4085-GF-A |  |  | DigiKey | 1 | €0.84
BP1 | Leistungseingang-Buchse | JACK-L-PC-10A-RA(R) |  |  | DigiKey | 1 | €3.24
BP2 | Leistungseingang-Buchse | PJ-082BH |  |  | DigiKey | 1 | €1.70
SP1 | Leistungskabel-Stecker | 50-00542 |  |  | DigiKey | 1 | €0.82
SP2 | Leistungskabel-Stecker | 50-00619 |  |  | DigiKey | 1 | €0.94
SP3 | Leistungskabel-Stecker | PP3-002B |  |  | DigiKey | 1 | €1.33
LK1 | Leistungskabel | 44A0221-16-9/9CS3030 |  |  | DigiKey | 6 | €12.24
Lk2 | Leistungskabel | CF881-15-02 |  |  | DigiKey | 6 | €17.22
BF1 | Buchse 4 pin, rechtwinkel. | S4B-XH-SM4-TB |  | https://www.digikey.de/de/products/detail/jst-sales-america-inc/S4B-XH-SM4-TB/1651064 | DigiKey | 3 | €2.07
BF1 | Buchse 2 pin, rechtwinkel. | S2B-PH-SM4-TB |  | https://www.digikey.de/de/products/detail/jst-sales-america-inc/S2B-PH-SM4-TB/926655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 | DigiKey | 9 | €4.77
BF1 | Buchse 3 pin, rechtwinkel. | S3B-XH-SM4-TB |  | https://www.digikey.de/de/products/detail/jst-sales-america-inc/S3B-XH-SM4-TB/1651065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 | DigiKey | 5 | €3.45
BF2 | Buchse rechtwinke. SET | - |  |  | Amazon | 1 | €17.14
BF2.1 | Buchse gerade (wird auf Pin-Reihen gesteckt) | - |  |  | Amazon | 1 | €8.05
BF3 | Pin-Reihen im rechten Winkel | - |  |  | Amazon | 1 | €7.55
BF4 | Buchse 4 pin, rechtwinkel. | S4B-XH-A-1 |  |  | DigiKey | 1 | €0.22
BF4 | Buchse 2 pin, rechtwinkel. | S3B-XH-A-1 |  |  | DigiKey | 4 | €0.72
BF4 | Buchse 3 pin, rechtwinkel. | S2B-XH-A-1 |  |  | DigiKey | 2 | €0.28
ST1 | 3x1 Stecker (Versorgungsspannung) | TS-103-T-A |  |  | DigiKey | 1 | €0.78
ST1 | 3x2 Stecker (Auswahl) | TD-103-T-A |  |  | DigiKey | 1 | €1.73
ST2 | 3x2 SMD Stecker (Microstepping) | M40-3200345R |  | https://www.digikey.at/en/products/detail/harwin-inc/M40-3200345R/2657728 | DigiKey |  | €0.00
ST2 | 2 Pin Bridge (Auswahl Microstepping) | 5013300200 |  | https://www.digikey.at/en/products/detail/molex-llc/5013300200/1531499 | DigiKey | 1 | €0.21
ST2 | 3x1 Stecker (Versorgungsspannung) | 665103131822 |  |  | DigiKey | 1 | €0.75
ST2 | 3x1 Bridge/Stecker (Auswahl) | 665003113322 |  |  | DigiKey | 1 | €0.20
ST3 | 3x2 Stecker/Pin Header (Microstepping) | FTSH-103-01-L-DH |  |  | DigiKey | 1 | €1.24
ST3 | 2 Pin Bridge (zur manuellen Auswahl) | M50-1900005 |  |  | DigiKey | 3 | €0.96
ST3 | 3 Pin Header | FTS-103-01-F-S |  |  | DigiKey | 2 | €1.40
 | Abstandhalter | 971070154 |  | https://www.digikey.de/de/products/detail/w%C3%BCrth-elektronik/971070154/9488609 | DigiKey | 8 | €7.04
 | Abstandhalter | 971110154 |  |  | DigiKey | 4 | €3.00
SV1 | Steckverbinder Female | BF100-16-A-D-1-0640-L-C |  | https://www.digikey.de/de/products/detail/gct/BF100-16-A-D-1-0640-L-C/16396992 | DigiKey | 4 | €2.28
SV1 | Steckverbinder Male | BF030-16A-B1-0360-0277-0600-LB |  | https://www.digikey.de/de/products/detail/gct/BF030-16A-B1-0360-0277-0600-LB/16397007 | DigiKey | 4 | €2.20
SV2 | Steckverbinder Female | HLE-107-02-L-DV | https://www.samtec.com/products/hle-107-02-l-dv | https://www.digikey.de/en/products/detail/samtec-inc/HLE-107-02-L-DV/6693078 | DigiKey | 2 | €5.20
SV2 | Steckverbinder Male | TSM-107-04-L-DV |  |  | DigiKey | 1 | €1.53
SV2 | Steckverbinder Male, Hoch | HW-07-08-L-D-250-SM |  |  | Mouser | 1 | €2.17
Lager | Widerstand | - |  | https://www.amazon.de/AUKENIEN-Widerstand-Sortiment-Resistor-Widerst%C3%A4nde/dp/B0B8CV56D7 | Amazon | 1 | €8.66
Lager | LED | - |  |  | Amazon | 1 | €5.99
Lager | Kapazitäten | - |  |  | Amazon | 1 | €18.14

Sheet: Sheet1
Alternative | Bezeichnung | Seriennummer | Kauf | Stückzahl | Gesamtpreis | Referenz
 | Raspberry Pi | Raspberry Pi 3B+ | DigikKey | 1 | €33.37 | \cite{RaspberryPi3BPlus_DigiKey2025}
 | Microchip | ATMEGA328P-AU | DigiKey | 1 | €2.55 | \cite{ATMEGA328P_AU}
 | USB-Serial Wandler | FT232RNL-TUBE | DigiKey | 1 | €4.60 | \cite{FT232RNL_USB_Serial}
 | Quarz-Oszillator für Microchip | ECS-160-18-4X-CKM | DigiKey | 1 | €0.41 | \cite{Quarz_ECS160}
 | Reset-Button | PTS647SM38SMTR2 LFS | DigiKey | 1 | €0.23 | \cite{Tactile_Switch_PTS647}
 | Schrittmotor | 14HM08-0504S | Stepperonline | 1 | €9.91 | \cite{Stepper_Nema14}
S1 | Schrittmotor-Treiber | DRV8825 | AZ-Delivery | 1 | €6.99 | \cite{DRV8825_Schrittmotor_Treiber}
 | Servo | MG90S | AZ-Delivery | 1 | €6.99 | \cite{Servo_MG90S}
BL | Nivellierungssensor | BLTouch Nivellierungssensor | 3D-Jake | 1 | €39.99 | \cite{BLTouch_Leveling_Sensor}
ACC3 | Beschleunigungssensor | Sunfounder GY-521 MPU-6050 | AZ-Delivery | 1 | €5.99 | \cite{MPU6050_GY521}
F2 | Lüfter | CFM-2507CF-1140-313 | DigiKey | 2 | €13.46 | \cite{Luefter_CFM2507CF_1140}
F2 | Lüfter | CFM-2507CF-0140-313 | DigiKey | 2 | €14.80 | \cite{Luefter_CFM2507CF_0140}
 | Temperaturelement | B57550G1103F005 | DigiKey | 4 | €10.00 | \cite{NTC_Thermistor_ABNTC0805}
ST_TEMP | 2 Pin Stecker f. Temperatursensor | 665002113322 | DigiKey | 4 | €0.52 | \cite{Connector_Housing_665002113322}
ST_TEMP | 2 Pin Buchse f. Temperatursensor | 665102131822 | DigiKey | 4 | €2.44 | \cite{Header_Pin_665102131822}
POW2 | 12-40V zu 40V Buck | TPS56837HRPAR | DigiKey | 1 | €2.34 | \cite{DC_DC_Regler_TPS56837}
POW2 | 12V zu 5V Buck | TPS565208DDCR | DigiKey | 1 | €1.17 | \cite{DC_DC_Regler_TPS565208}
 | Spule 12V Buck | SPM10040T-4R7M-HZ | DigiKey | 1 | €1.78 | \cite{Induktor_SPM10040T}
 | Spule 5V Buck | IHLP2525CZER3R3M11 | DigiKey | 1 | €0.95 | \cite{Induktor_IHLP2525CZER3R3M11}
 | P-MOSFET als Verpolungsschutz | SQJ409EP-T1_GE3 | DigiKey | 1 | €1.56 | \cite{MOSFET_SQJ409EP}
 | Zener Diode | SZ1SMB5927BT3G | DigiKey | 1 | €0.47 | \cite{Zenerdiode_SZ1SMB5927BT3G}
 | TSV Diode | 824521241 | Digikey | 2 | €0.60 | \cite{TVS_Diode_824521241}
 | N-MOSFET als Fan-Ansteuerung | RJK0456DPB-00#J5 | DigiKey | 2 | €5.82 | \cite{MOSFET_RJK0456DPB}
 | Fan-Controller mit Richtungswechsel | TPM16050-S6TR | DigiKey | 1 | €0.60 | \cite{Motor_Driver_TPM16050}
 | USB-C Kabel | A-USB31C-20A-150A | DigiKey | 1 | €9.25 | \cite{USB_Cable_A_USB31C_20A_150A}
 | USB-C Buchse | USB4085-GF-A | DigiKey | 1 | €0.84 | \cite{USB_Connector_USB4085_GF_A}
BP2 | Leistungseingang-Buchse | PJ-082BH | DigiKey | 1 | €1.70 | \cite{Power_Connector_PJ_082BH}
SP2 | Leistungskabel-Stecker | 50-00619 | DigiKey | 1 | €0.94 | \cite{Power_Connector_50_00619}
Lk2 | Leistungskabel | CF881-15-02 | DigiKey | 6 | €17.22 | \cite{Multiconductor_Cable_CF881_15_02}
BF4 | Buchse 4 pin, rechtwinkel. | S4B-XH-A-1 | DigiKey | 1 | €0.22 | \cite{Header_Pin_S4B_XH_A_1}
BF4 | Buchse 2 pin, rechtwinkel. | S3B-XH-A-1 | DigiKey | 4 | €0.72 | \cite{Header_Pin_S3B_XH_A_1}
BF4 | Buchse 3 pin, rechtwinkel. | S2B-XH-A-1 | DigiKey | 2 | €0.28 | \cite{Header_Pin_S2B_XH_A_1}
ST3 | 3x2 Stecker/Pin Header (Microstepping) | FTSH-103-01-L-DH | DigiKey | 1 | €1.24 | \cite{Header_Pin_FTSH_103}
ST3 | 2 Pin Bridge (zur manuellen Auswahl) | M50-1900005 | DigiKey | 3 | €0.96 | \cite{Shunt_Jumper_M50_1900005}
ST3 | 3 Pin Header | FTS-103-01-F-S | DigiKey | 2 | €1.40 | \cite{Header_Pin_665102131822}
 | Abstandhalter | 971070154 | DigiKey | 8 | €7.04 | \cite{Board_Spacer_971070154}
 | Abstandhalter | 971110154 | DigiKey | 4 | €3.00 | \cite{Board_Spacer_971110154}
SV2 | Steckverbinder Female | HLE-107-02-L-DV | DigiKey | 2 | €5.20 | \cite{Header_Socket_HLE_107}
SV2 | Steckverbinder Male | TSM-107-04-L-DV | DigiKey | 1 | €1.53 | \cite{Header_Pin_TSM_107}
SV2 | Steckverbinder Male, Hoch | HW-07-08-L-D-250-SM | Mouser | 1 | €2.17 | \cite{Connector_HW_07_08}


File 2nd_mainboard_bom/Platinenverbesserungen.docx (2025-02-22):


Die nicht-verbundenen Pins werden so angezeigt im Layout, dass sie verbunden werden müssen. Diese Verbindungen unbedingt wieder rauslöschen!

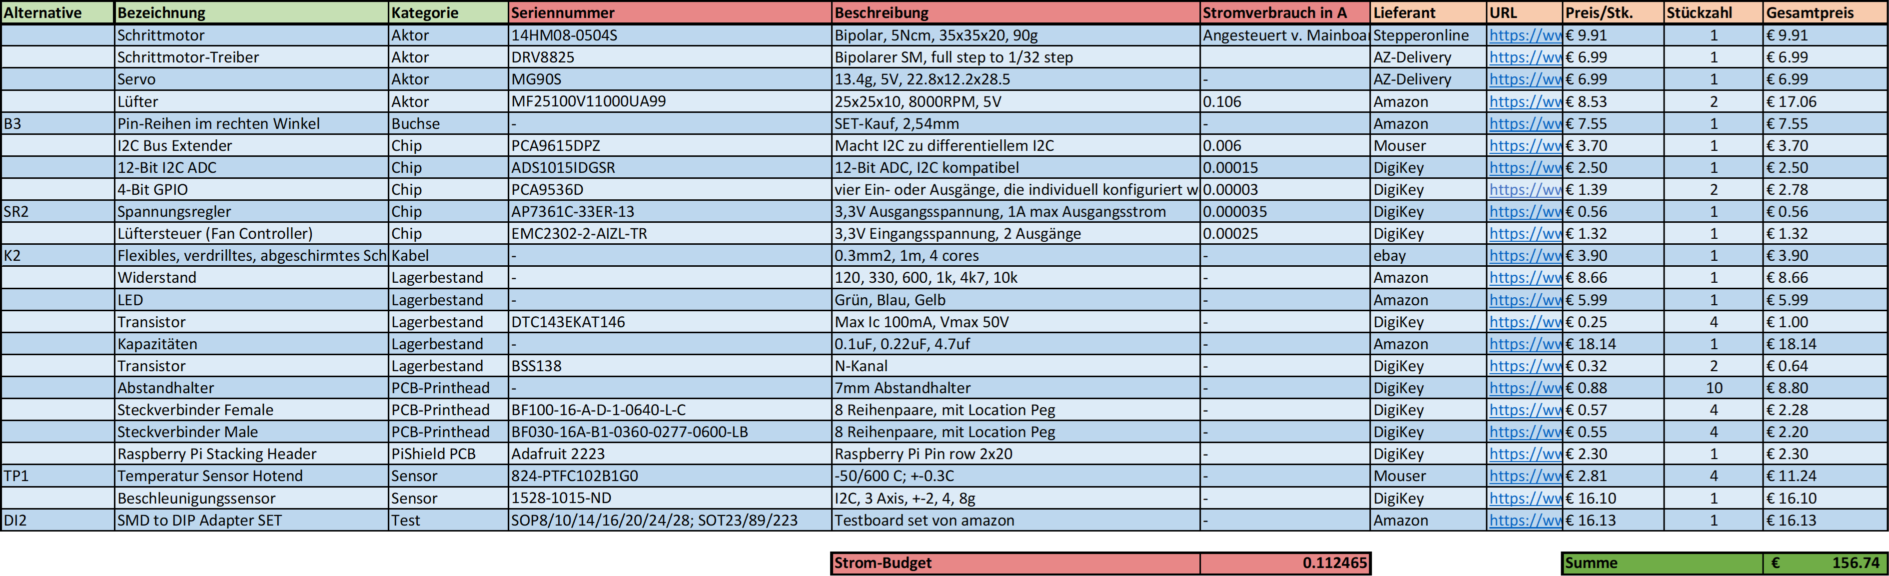
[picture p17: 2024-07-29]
2nd-mainboard-pcb/2nd_mainboard_bom/Nur eine Alternative.png

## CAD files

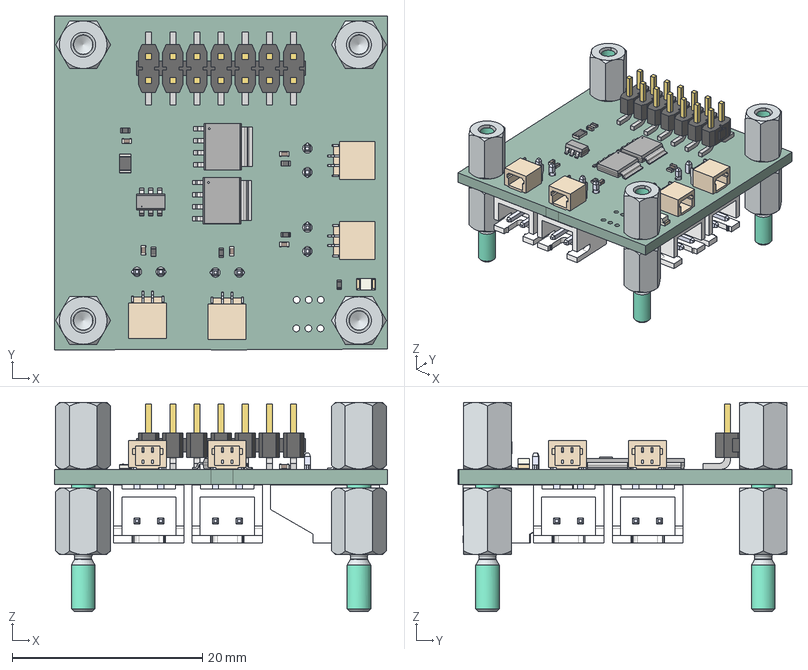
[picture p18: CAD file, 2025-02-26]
2nd-mainboard-pcb/cad/Modul_Fans.stp
35.0 x 35.1 x 22.0 mm
SMBJ-ALL
R_0402_1005Metric_7 x 6
SMBJ-ALL_1
PinHeader_2x03_P254mm_Vertical
C_0805_2012Metric_1
R_0805_2012Metric_1
TestPoint_Loop_D3.80mm_Drill2.5mm_1
TSM-107-04-L-DV_1
TSM-107-04-L-DV_3
C_0805_2012Metric_3
C_0402_1005Metric_1 x 5
6651xx131822 x 4
DRV8825 STEPPER MOTOR DRIVER CARRIER
LED_0805_2012Metric_1
C_1210_3225Metric_1
MBRS360BT3G
R_0402_1005Metric_1
LED_0805_2012Metric_3
TQFP_32_7x7mm_P08mm
R_0402_1005Metric_3
PinSocket_1x02_P2.54mm_Vertical_1
SQJ148EP-T1_GE3
TestPoint_Loop_D3.80mm_Drill2.5mm_3
C_1210_3225Metric_3
CUI_DEVICES_PJ-082BH
S4B-XH-A-1_1
JST_S3B_XH_A
R_0402_1005Metric_5
HC-49USX(-4X)
USB_C_Receptacle_GCT_USB4085_1
JST_S3B_XH_A_1
PinSocket_1x04_P2.54mm_Vertical_1
R_0402_1005Metric_9
R_0402_1005Metric_11
SPM10040T-100M-HZ
R_0603_1608Metric_1
C_0402_1005Metric_3
R_0402_1005Metric_13
C_1210_3225Metric_5
C_0805_2012Metric_5
HLE-107-02-L-DV_1
R_0402_1005Metric_15
C_0805_2012Metric_7
C_0805_2012Metric_9
SOT_23_6
R_0402_1005Metric_17
S2B-XH-A-1(LF)(SN) x 4
R_0402_1005Metric_19
C_0402_1005Metric_5
R_0402_1005Metric_21
C_0402_1005Metric_7
6651xx131822_1
C_0402_1005Metric_9
C_0805_2012Metric_11
C_1210_3225Metric_7
C_0402_1005Metric_11
C_0402_1005Metric_13
C_0402_1005Metric_15
C_0805_2012Metric_13
C_0402_1005Metric_17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

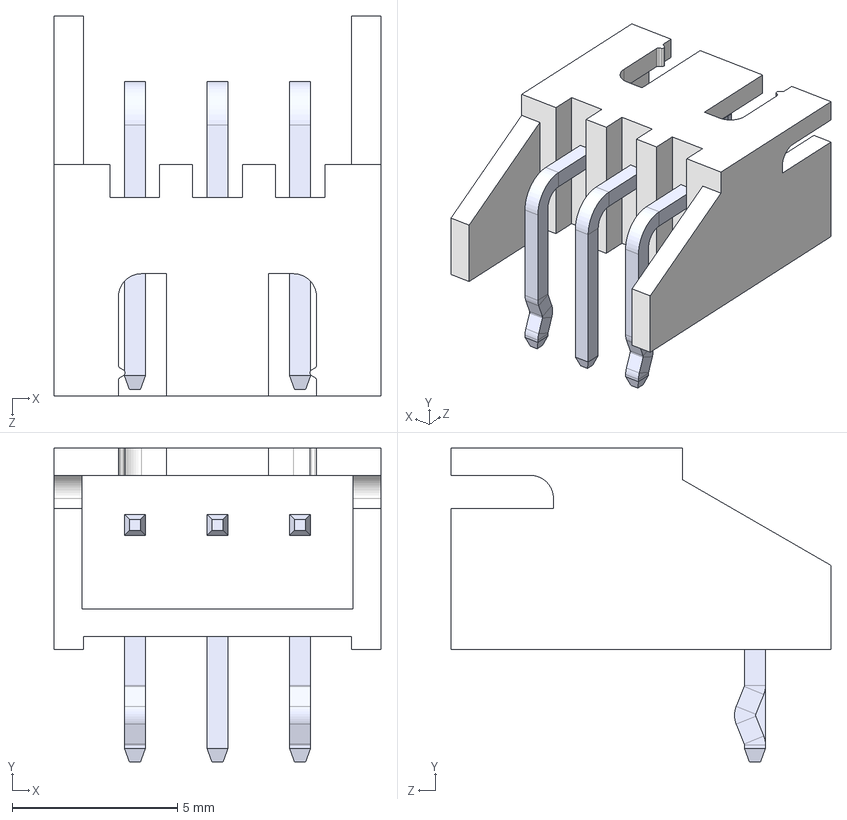
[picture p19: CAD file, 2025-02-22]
2nd-mainboard-pcb/imported_components/S3B_XH_A_LF__SN_/KiCADv6/S3B-XH-A.STEP
9.90 x 9.50 x 11.5 mm
SxB-XH-A_3
pin^SxB-XH-A ass_bent x 2
pin^SxB-XH-A ass

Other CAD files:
2nd-mainboard-pcb/cad/Elektronik_Gesamtbaugruppe.iam
2nd-mainboard-pcb/cad/Modul_Fans/1_1.ipt
2nd-mainboard-pcb/cad/Modul_Fans/665102131822.iam
2nd-mainboard-pcb/cad/Modul_Fans/6651xx131822.ipt
2nd-mainboard-pcb/cad/Modul_Fans/C_0402_1005Metric.iam
2nd-mainboard-pcb/cad/Modul_Fans/C_0402_1005Metric.ipt
2nd-mainboard-pcb/cad/Modul_Fans/Download_STEP_971070154_rev1.iam
2nd-mainboard-pcb/cad/Modul_Fans/LED_0805_2012Metric.iam
2nd-mainboard-pcb/cad/Modul_Fans/LED_0805_2012Metric.ipt
2nd-mainboard-pcb/cad/Modul_Fans/LFPAK_REN.iam
2nd-mainboard-pcb/cad/Modul_Fans/Modul_Fans.iam
2nd-mainboard-pcb/cad/Modul_Fans/R_0402_1005Metric.iam
2nd-mainboard-pcb/cad/Modul_Fans/R_0402_1005Metric.ipt
2nd-mainboard-pcb/cad/Modul_Fans/R_0805_2012Metric.iam
2nd-mainboard-pcb/cad/Modul_Fans/R_0805_2012Metric.ipt
2nd-mainboard-pcb/cad/Modul_Fans/S2B-XH-A-1(LF)(SN).ipt
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

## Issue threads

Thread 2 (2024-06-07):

Kabel heraussuchen

JanHTL, 2024-06-07:
Kabel auf suchen fuer i2c leitung

GodGotzi, 2024-06-08:
anbieter: phoenix contact

fand ich am besten von der Auswahl her, hab da nur Angst , dass diese Kabel teuer werden können

GodGotzi, 2024-06-08:
Ist es sinnvoll eine Netzwerk buchse auf der Platine zu platzieren?

Closed 2024-07-30.

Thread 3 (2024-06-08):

beschleunigungssensor

JanHTL, 2024-06-08:
beschleunigungssensor auswwählen und in projekt einbinden. Anschließbar machen

GodGotzi, 2024-06-08:
adxl335 find ich gut dafür gibt es fertige entwickler boards, gibt aber noch günstigere Alternativen

GodGotzi, 2024-06-08:
adxl335 adafruit

GodGotzi, 2024-06-08:
https://www.amazon.de/Beschleunigungssensor-Accelerometer-Digitales-Schwerkraft-%C3%9Cbertragung/dp/B0CMHTQF68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

JanHTL, 2024-06-08:
sieht gut aus für den anfang werd ma den mal verbauen. von den anschlüssen her sind sie grötenteils sehr ähnlich

Closed 2024-06-08.

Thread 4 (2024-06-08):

frage zu on off fans

JanHTL, 2024-06-08:
kann man diese direkt vom LED Driver zur Schaltung schliessen, wo bei den anderen das pwm signal kommt?

GodGotzi, 2024-06-08:
wie meinst du das?

GodGotzi, 2024-06-08:
wir brauchen fix nen mosfet oder transistor zum schalten. Wenn ich mich net ganz täusche hat der led driver pro pin max 30ma. Bedeutet wir brauchen ganz sicher noch einen Transistor oder Mosfet.

JanHTL, 2024-06-08:
> wir brauchen fix nen mosfet oder transistor zum schalten. Wenn ich mich net ganz täusche hat der led driver pro pin max 30ma. Bedeutet wir brauchen ganz sicher noch einen Transistor oder Mosfet.

ja fix
können wir den transistor nehmen tho den wir eh schon verwenden für die anderen die wir mit pwm antreiben

GodGotzi, 2024-06-08:
ja könnma

JanHTL, 2024-06-08:
> ja könnma

supi supi dann kann is so lassen wies is

Closed 2024-06-08.

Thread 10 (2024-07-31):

dimensions

JanHTL, 2024-07-31:
add dimensions to pcb for better understanding

JanHTL, 2024-07-31:
sadly not possible, the dimensions are only flowing in space https://forum.kicad.info/t/drawing-a-pcb-to-precise-dimensions/18629/3

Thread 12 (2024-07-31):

github workflow

JanHTL, 2024-07-31:
write github workflow to generate p9dfs of the schematic and PCB and merge them togeheter to have the whole project visible as pdf after every commit

JanHTL, 2024-07-31:
currently trying this out, working on it.

Closed 2024-07-31.

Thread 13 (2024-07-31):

datasheet validation

JanHTL, 2024-07-31:
go through data sheets and make sure to check that the layout of e.g. the capazities are correctly implemented. the placement is important, sometimes they need to be very close to the incoming power to smoothen the signal, said a wise man named Haris

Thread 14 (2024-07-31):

datasheet validation

JanHTL, 2024-07-31:
go through data sheets and make sure to check that the layout of e.g. the capazities are correctly implemented. the placement is important, sometimes they need to be very close to the incoming power to smoothen the signal, said a wise man named Haris

Closed 2024-07-31.

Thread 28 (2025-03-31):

wrong symbol

JanHTL, 2025-03-31:
symbol vom 12V schaltregler ausbessern (V3 erschaffen)

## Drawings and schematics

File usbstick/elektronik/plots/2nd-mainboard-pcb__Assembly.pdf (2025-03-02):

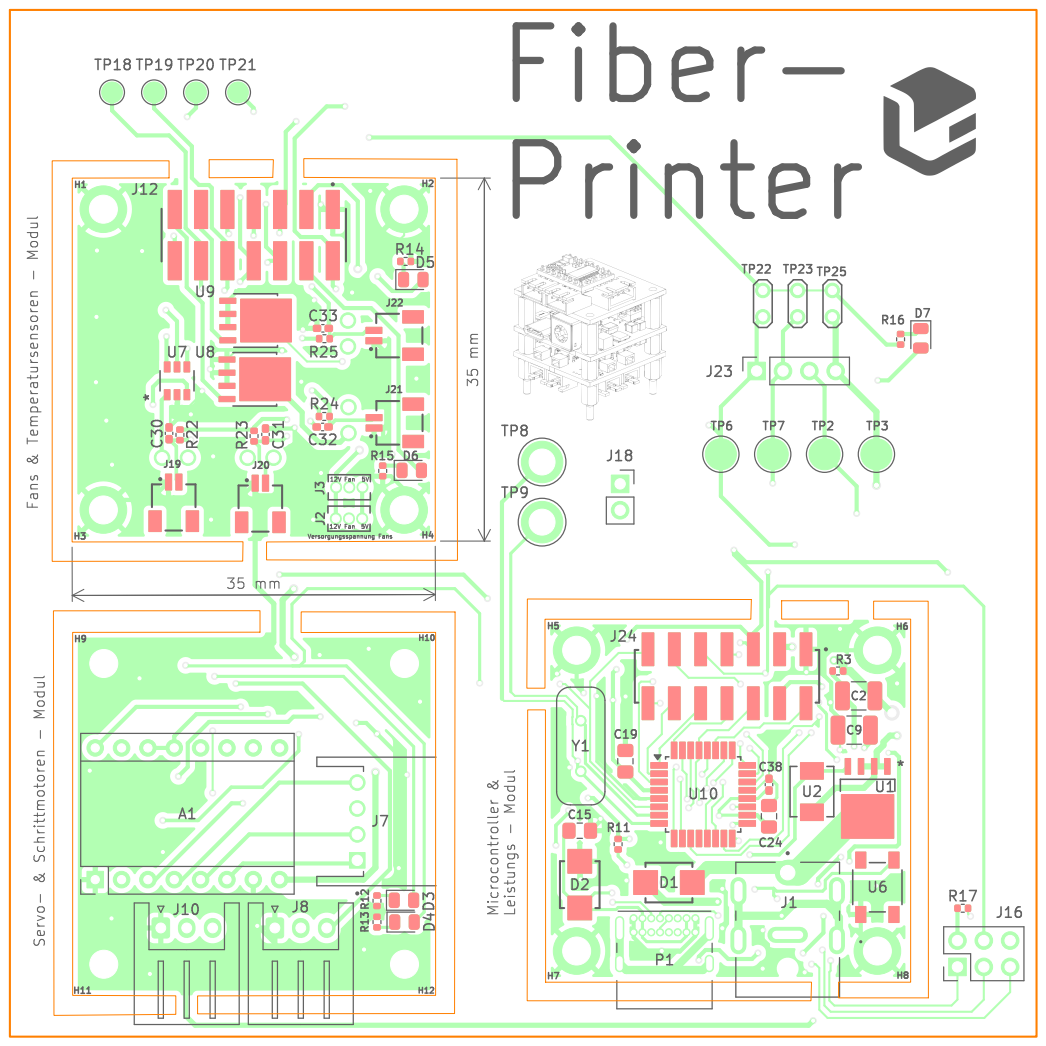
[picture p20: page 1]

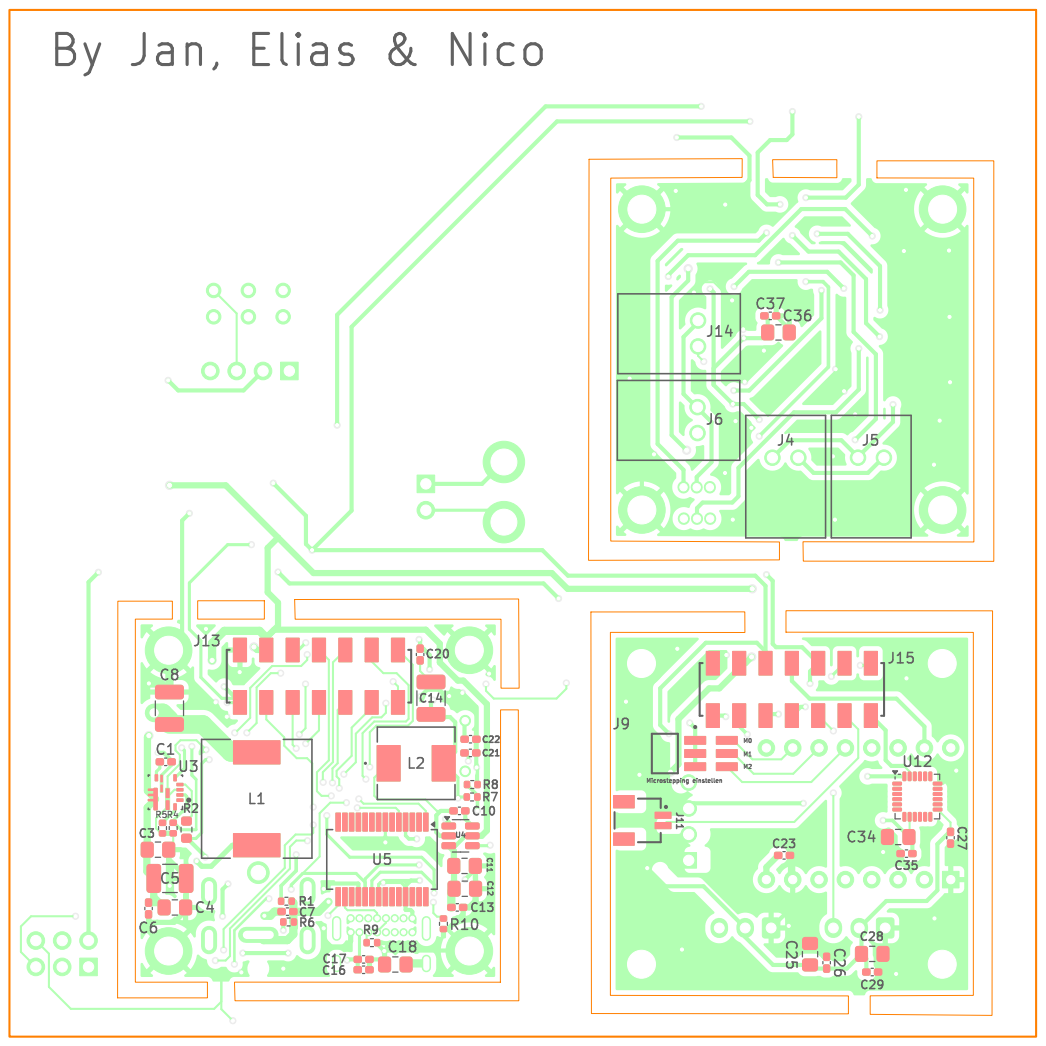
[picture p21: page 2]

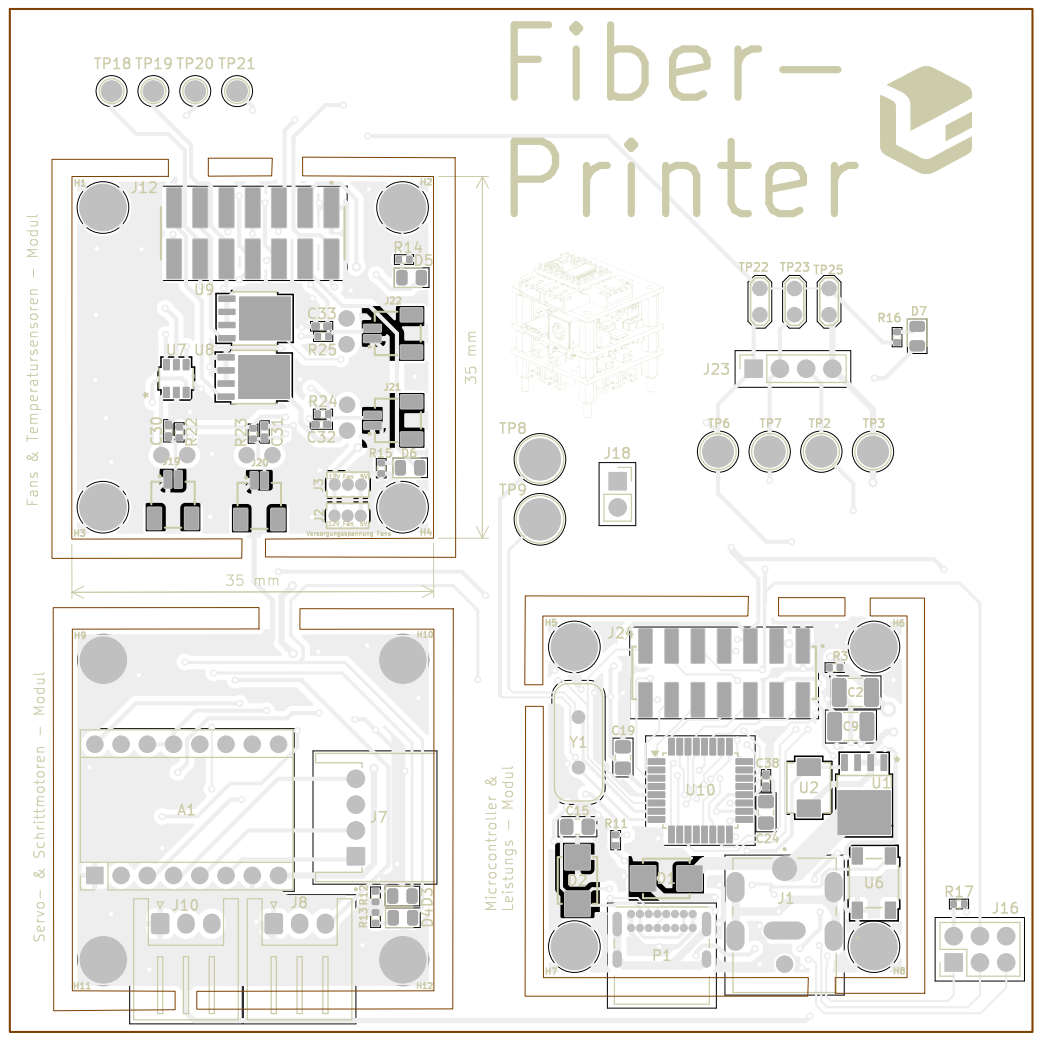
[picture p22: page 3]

Servo- & Schrittmotoren - Modul Fan J19 Fiber-

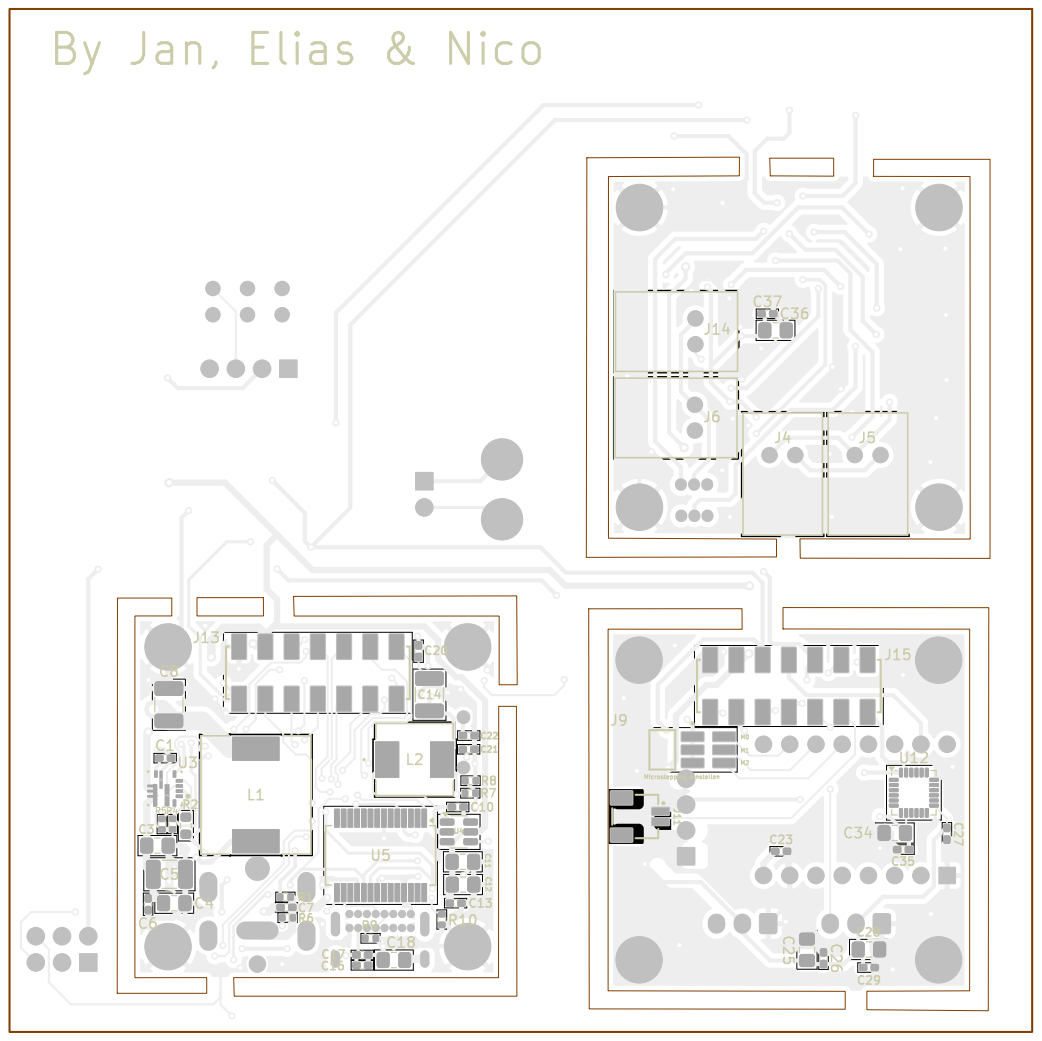
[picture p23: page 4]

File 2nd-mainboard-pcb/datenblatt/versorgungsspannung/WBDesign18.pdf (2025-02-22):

## WEBENCH ® Design Report

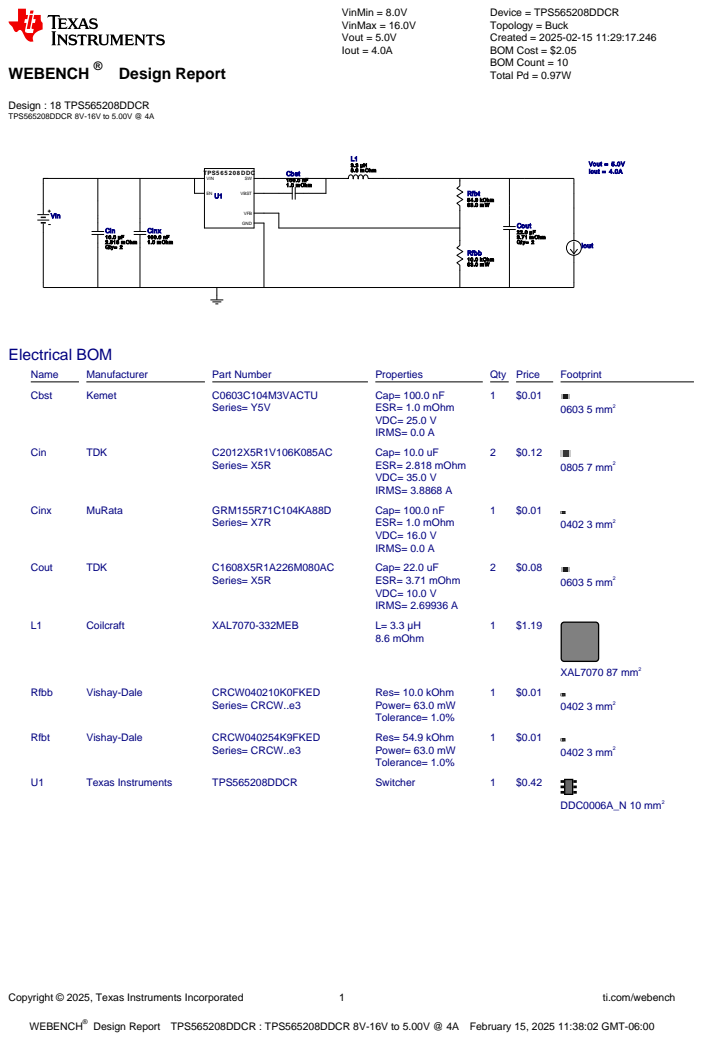
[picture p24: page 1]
Copyright © 2025, Texas Instruments Incorporated; ti.com/webench; WEBENCH®; Design : 18 TPS565208DDCR TPS565208DDCR 8V-16V to 5.00V @ 4A; VinMin = 8.0V VinMax = 16.0V Vout = 5.0V Iout = 4.0A; Device = TPS565208DDCR Topology = Buck Created = 2025-02-15 11:29:17.246 BOM Cost = $2.05 BOM Count = 10 Total Pd = 0.97W; Cbst 100.0 nF 1.0 m Ohm; Cin 10.0 µF 2.818 m Ohm Qty= 2; Cinx 100.0 nF 1.0 m Ohm; Cout 22.0 µF 3.71 m Ohm Qty= 2; L1 3.3 µH 8.6 m Ohm; Rfbb 10.0 kOhm 63.0 m W; Rfbt 54.9 kOhm 63.0 m W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

Design Report TPS565208DDCR : TPS565208DDCR 8V-16V to 5.00V @ 4A February 15, 2025 11:38:02 GMT-06:00

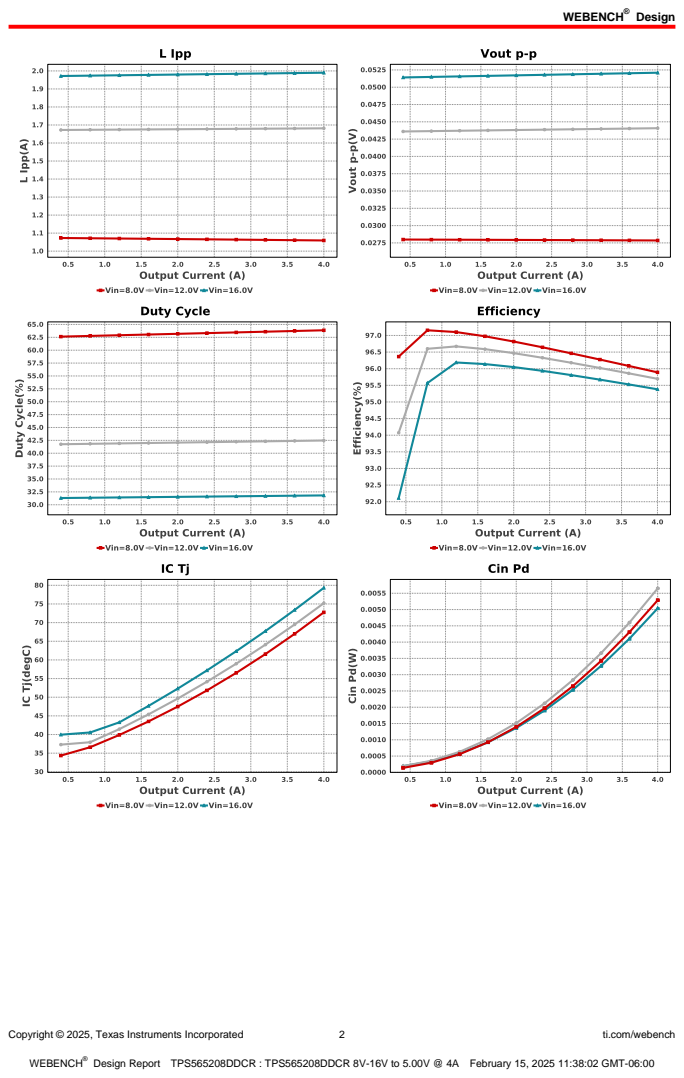
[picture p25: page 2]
Design; Copyright © 2025, Texas Instruments Incorporated; ti.com/webench

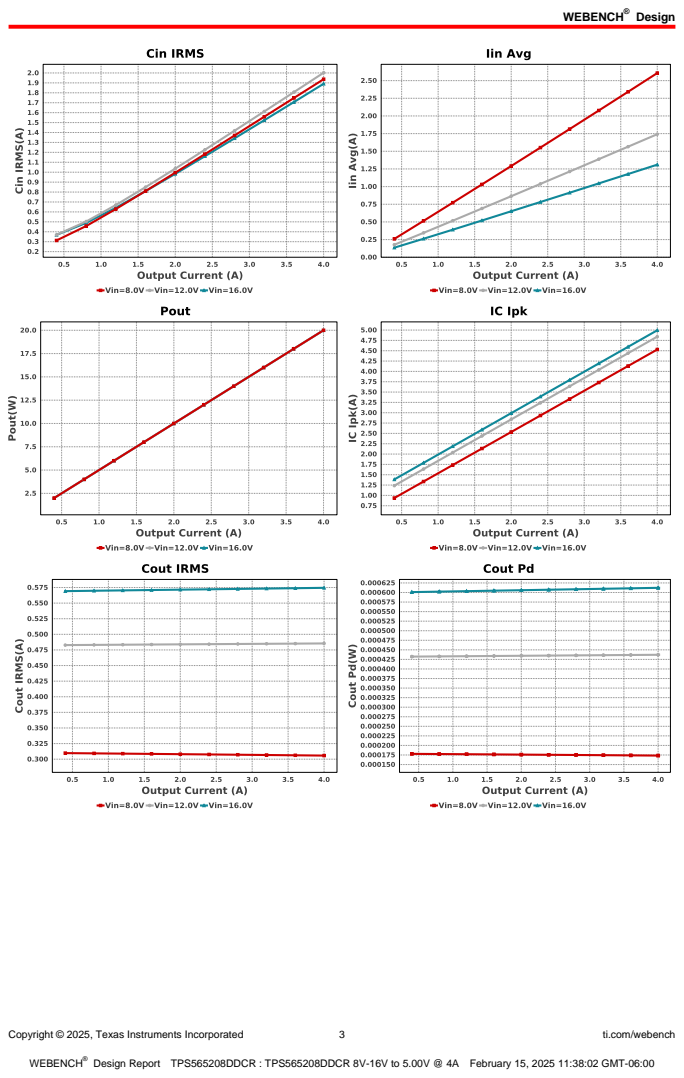
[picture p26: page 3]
Copyright © 2025, Texas Instruments Incorporated; ti.com/webench

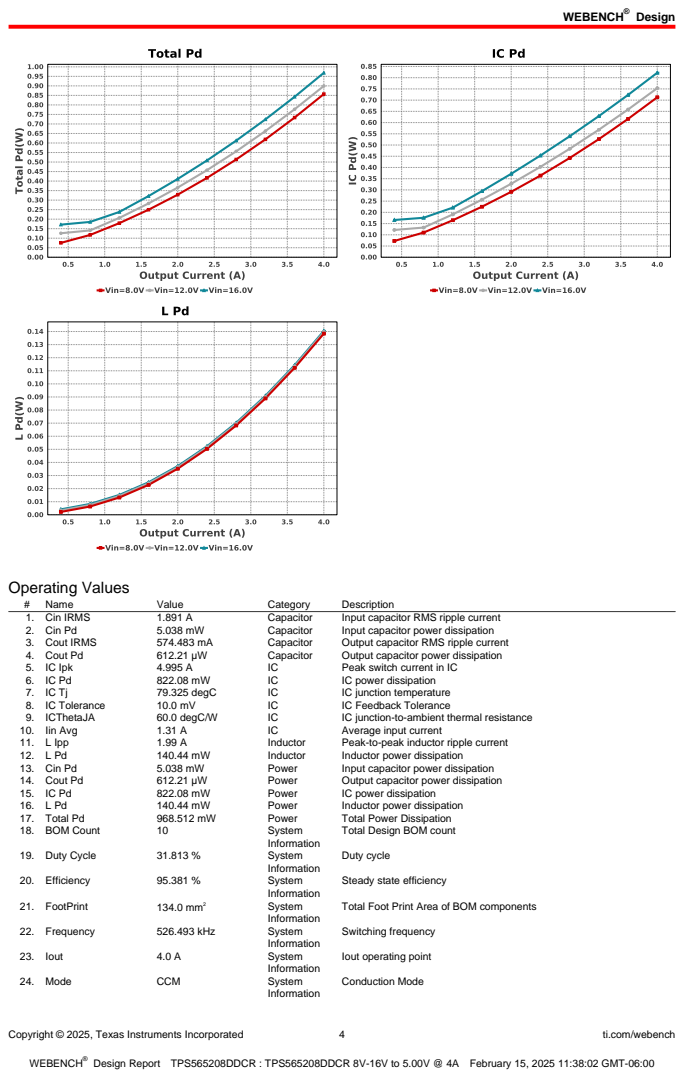
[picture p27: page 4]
Copyright © 2025, Texas Instruments Incorporated; ti.com/webench; Operating Values; Name; Value; Category; Description; 1. Cin IRMS; Capacitor; Input capacitor RMS ripple current; 2. Cin Pd; Input capacitor power dissipation; 3. Cout IRMS; Output capacitor RMS ripple current; 4. Cout Pd; Output capacitor power dissipation; 5. IC Ipk; Peak switch current in IC; IC power dissipation; 79.325 degC; IC junction temperature; 8. IC Tolerance; IC Feedback Tolerance; 9. ICThetaJA; 60.0 degC/W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

Total Design BOM count

Steady state efficiency

Total Foot Print Area of BOM components

Iout operating point

Copyright © 2025, Texas Instruments Incorporated | 5 | ti.com/webench
# | Name | Value | Category | Description

25. Pout | 20.0 W | System
| | | Information | Total output power
26. Total BOM | $2.05 | System
| | | Information | Total BOM Cost
27. Vin | 16.0 V | System
| | | Information | Vin operating point
28. Vout | 5.0 V | System
| | | Information | Operational Output Voltage
29. Vout Actual | 4.965 V | System
| | | Information | Vout Actual calculated based on selected voltage divider resistors
30. Vout Tolerance | 3.038 % | System
| | | Information | Vout Tolerance based on IC Tolerance (no load) and voltage divider resistors if applicable
31. Vout p-p | 52.096 mV | System
| | | Information | Peak-to-peak output ripple voltage

## Design Inputs

Name | Value | Description
Iout | 4.0 | Maximum Output Current
VinMax | 16.0 | Maximum input voltage
VinMin | 8.0 | Minimum input voltage
Vout | 5.0 | Output Voltage
| base_pn | | TPS565208 | Base Product Number
source | DC | Input Source Type
Ta | 30.0 | Ambient temperature


Copyright © 2025, Texas Instruments Incorporated | 6 | ti.com/webench

## Assembly

## Component Testing

Some published data on components in datasheets such as Capacitor ESR and Inductor DC resistance is based on conservative values that will guarantee that the components always exceed the specification. For design purposes it is usually better to work with typical values. Since this data is not always available it is a good practice to measure the Capacitance and ESR values of Cin and Cout, and the inductance and DC resistance of L1 before assembly of the board. Any large discrepancies in values should be electrically simulated in WEBENCH to check for instabilities and thermally simulated in WebTHERM to make sure critical temperatures are not exceeded.

## Soldering Component to Board

If board assembly is done in house it is best to tack down one terminal of a component on the board then solder the other terminal. For surface mount parts with large tabs, such as the DPAK, the tab on the back of the package should be pre-tinned with solder, then tacked into place by one of the pins. To solder the tab town to the board place the iron down on the board while resting against the tab, heating both surfaces simultaneously. Apply light pressure to the top of the plastic case until the solder flows around the part and the part is flush with the PCB. If the solder is not flowing around the board you may need a higher wattage iron (generally 25W to 30W is enough).
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

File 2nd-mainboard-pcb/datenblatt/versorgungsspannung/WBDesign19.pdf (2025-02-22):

## WEBENCH ® Design Report

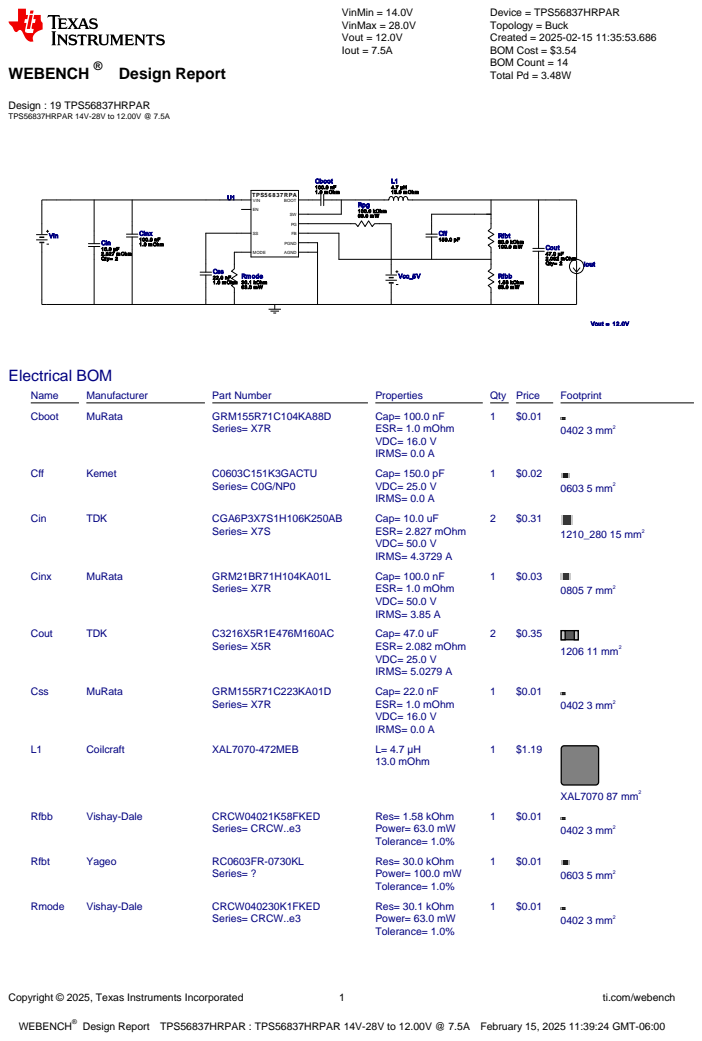
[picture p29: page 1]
Copyright © 2025, Texas Instruments Incorporated; ti.com/webench; WEBENCH®; Design : 19 TPS56837HRPAR TPS56837HRPAR 14V-28V to 12.00V @ 7.5A; VinMin = 14.0V VinMax = 28.0V Vout = 12.0V Iout = 7.5A; Device = TPS56837HRPAR Topology = Buck Created = 2025-02-15 11:35:53.686 BOM Cost = $3.54 BOM Count = 14 Total Pd = 3.48W; Rm ode 30.1 kOhm 63.0 m W; Rpg 100.0 kOhm 63.0 m W; Cin 10.0 µF 2.827 m Ohm Qty= 2; Cout 47.0 µF 2.082 m Ohm Qty= 2; Rfbb 1.58 kOhm 63.0 m W; Rfbt 30.0 kOhm 100.0 m W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

Design Report TPS56837HRPAR : TPS56837HRPAR 14V-28V to 12.00V @ 7.5A February 15, 2025 11:39:24 GMT-06:00

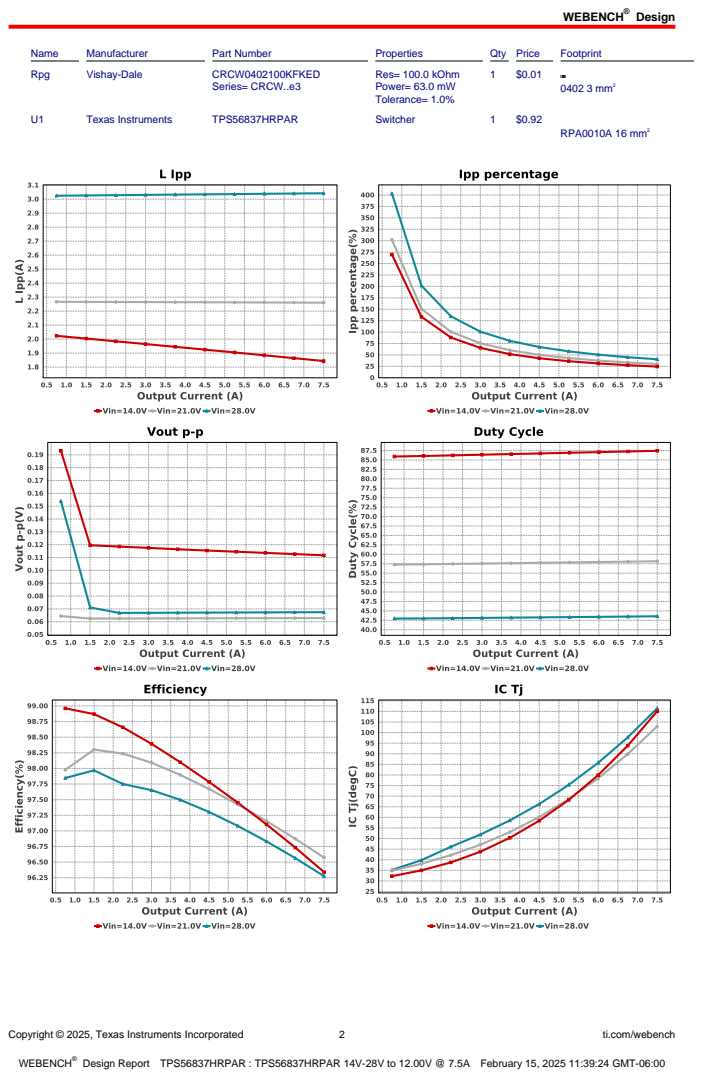
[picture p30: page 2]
Design; Copyright © 2025, Texas Instruments Incorporated; ti.com/webench; Name; Manufacturer; Part Number; Properties; Qty Price; Footprint; Rpg; Vishay-Dale; CRCW0402100KFKED; Series= CRCW..e3; Res= 100.0 kOhm Power= 63.0 mW Tolerance= 1.0%; 0402 3 mm²; Texas Instruments; TPS56837HRPAR; Switcher; RPA0010A 16 mm²

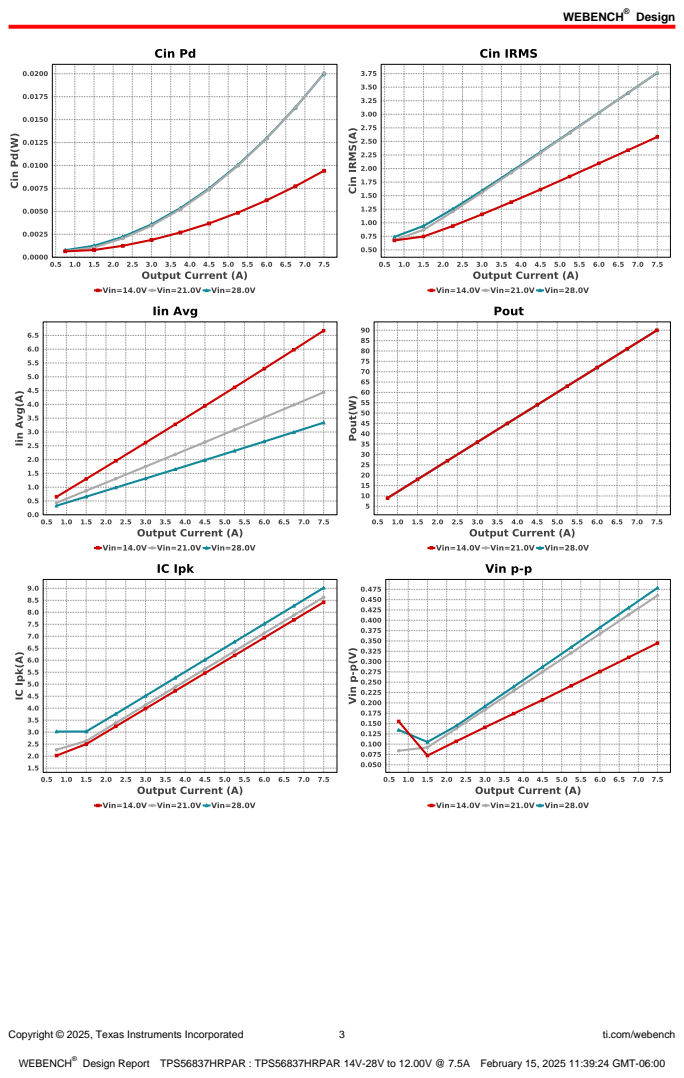
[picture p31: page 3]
Copyright © 2025, Texas Instruments Incorporated; ti.com/webench

Copyright © 2025, Texas Instruments Incorporated; ti.com/webench; Operating Values; Name; Value; Category; Description; 1. Cin IRMS; Capacitor; Input capacitor RMS ripple current; 2. Cin Pd; Input capacitor power dissipation; 3. Cout IRMS; Output capacitor RMS ripple current; 4. Cout Pd; Output capacitor power dissipation; 5. IC Ipk; Peak switch current in IC; IC power dissipation; 111.426 degC; IC junction temperature; 8. IC Tolerance; IC Feedback Tolerance; 9. ICThetaJA; 30.0 degC/W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

Copyright © 2025, Texas Instruments Incorporated | 5 | ti.com/webench
# | Name | Value | Category | Description

11. Ipp percentage | 40.566 % | Inductor | Inductor ripple current percentage (with respect to average inductor
| | | | current)
12. L Ipp | 3.042 A | Inductor | Peak-to-peak inductor ripple current
13. L Pd | 741.28 mW | Inductor | Inductor power dissipation
14. Cin Pd | 20.024 mW | Power | Input capacitor power dissipation
15. Cout Pd | 803.0 µW | Power | Output capacitor power dissipation
16. IC Pd | 2.714 W | Power | IC power dissipation
17. L Pd | 741.28 mW | Power | Inductor power dissipation
18. Total Pd | 3.481 W | Power | Total Power Dissipation
19. BOM Count | 14 | System
| | | Information | Total Design BOM count
20. Duty Cycle | 43.569 % | System
| | | Information | Duty cycle
21. Efficiency | 96.276 % | System
| | | Information | Steady state efficiency
22. FootPrint | 186.0 mm² | System
| | | Information | Total Foot Print Area of BOM components
23. Frequency | 479.865 kHz | System
| | | Information | Switching frequency
24. Iout | 7.5 A | System
| | | Information | Iout operating point
25. Mode | CCM | System
| | | Information | Conduction Mode
26. Pout | 90.0 W | System
| | | Information | Total output power
27. Total BOM | $3.54 | System
| | | Information | Total BOM Cost
28. Vin | 28.0 V | System
| | | Information | Vin operating point
29. Vin p-p | 478.654 mV | System
| | | Information | Peak-to-peak input voltage
30. Vout | 12.0 V | System
| | | Information | Operational Output Voltage
31. Vout Actual | 11.992 V | System
| | | Information | Vout Actual calculated based on selected voltage divider resistors
32. Vout Tolerance | 2.938 % | System
| | | Information | Vout Tolerance based on IC Tolerance (no load) and voltage divider resistors if applicable
33. Vout p-p | 67.441 mV | System
| | | Information | Peak-to-peak output ripple voltage

## Design Inputs

Name | Value | Description
Iout | 7.5 | Maximum Output Current
VinMax | 28.0 | Maximum input voltage
VinMin | 14.0 | Minimum input voltage
Vout | 12.0 | Output Voltage
| base_pn | | TPS56837H | Base Product Number
source | DC | Input Source Type
Ta | 30.0 | Ambient temperature


Copyright © 2025, Texas Instruments Incorporated | 6 | ti.com/webench

## Assembly
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

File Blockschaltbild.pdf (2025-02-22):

Mainboard Druck; RÜHE; für Treiber; Faservorschub; 12CLeitung; 12C für; Heateliment; Platine Druckkopf

seriguschnitt
Servo BC LEiLLEE.EE ta















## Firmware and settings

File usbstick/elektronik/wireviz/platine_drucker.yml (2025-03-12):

connectors:
  J1:
    type: "Leistungseingang"
    pins: [1, 2, SH1, SH2, SH3, SH4]
    pinlabels: [+24 V, GND2, GND3, GND3, GND3, GND3, ]
    manufacturer: "Same Sky "
    mpn: '<a href="https://www.digikey.de/en/products/detail/same-sky-formerly-cui-devices/PJ-082BH/3477156">PJ-082BH  </a>'
    supplier: Digikey
    spn: "3477156  "
  J2:
    type: "3D-Drucker-Netzteil "
    pins: [1, 2, 3]
    pinlabels: [+24 V, GND, SHIELD]

cables:
  "CF881-15-02":
    wirecount: 2
    gauge: 1.5 mm²
    length: 2.0  # Falls die Kabellänge bekannt ist, sonst entfernen
    category: shielded
    color_code: DIN # auto-assign colors based on DIN 47100
    shield:
      type: braid
      material: tin-plated copper
      coverage: 60
    color: BK  # Mantelfarbe (Jet Black ähnlich RAL 9005)
    manufacturer: Igus
    mpn: CF881-15-02
    notes: "Flexibles Steuerkabel mit PVC-Mantel, geschirmt   "
    # supplier: Cables R Us
    # spn: 999-888-777
    # pn: CAB1
    # image:
    #   src: resources/cable-BK+WH+numbered+shield.png
    #   height: 70  # Bildgröße leicht verkleinern
    #   caption: Querschnitt

connections:
  -
    - J2: [1, 2]
    - CF881-15-02: [1, 2]
    - J1: [1, 2]
  -
    - CF881-15-02: [s, s, s, s]
    - J1: [SH1, SH2, SH3, SH4]
  -
    - J2: [3]
    - CF881-15-02: [s]
# Shield nur an einer seite verbinden um brummschleifen zu vermeiden

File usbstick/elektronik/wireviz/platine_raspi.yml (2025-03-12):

connectors:
  Raspberry_Pi:
    type: USB-A Buchse
    subtype: USB2.0
    # subtype: usb-a  # Oder "usb-micro" für den Micro-USB-Anschluss des Raspberry Pi
    pins: [1, 2, 3, 4, 5]
    pinlabels: [VBUS (5 V), D-, D+, GND, Shield]
  P1:
      type: "USB-C Buchse "
      pins: [A1, A4, A5, A6, A7, A8, A9, A12, B1, B4, B5, B6, B7, B8, B9, B12, S1, ]
      pinlabels: [GND, AREF, Net-(P1-CC1), USBD+, USBD-, SBU1, AREF, GND, GND, AREF, Net-(P1-CC2), USBD+, USBD-, SBU2, AREF, GND, Net-(P1-SHIELD), ] 
      subtype: USB2.0
      manufacturer: '<a href="https://gct.co/">GCT</a>'
      mpn: '<a href="https://www.digikey.at/en/products/detail/gct/USB4085-GF-A/9859662">USB4085-GF-A</a>'
      supplier: Digikey
      spn: 9859662  

cables:
  "USB_Cable":
    wirecount: 4
    gauge: 28 AWG
    # gauge: 28 AWG (Data) / 24 AWG (Power)  # Typische Werte für USB-Kabel
    length: 1.0  # Länge in Metern, anpassen falls bekannt
    category: shielded
    # show_equiv: true
    color_code: DIN # auto-assign colors based on DIN 47100
    shield:
      type: braid
      material: tin-plated copper
      coverage: 85  # Typischer Wert für USB-Kabel
    color: BK  # Mantelfarbe (Schwarz)
    manufacturer: Generic  # Falls ein Hersteller bekannt ist, ersetzen
    mpn: USB_CABLE_XYZ  # Falls bekannt, ersetzen
    notes: "USB-Kabel für Daten- und Stromübertragung"
    # wires:
    #   - color: RD
    #     signal: "VBUS (5 V)"
    #   - color: WH
    #     signal: "D-"
    #   - color: GN
    #     signal: "D+"
    #   - color: BK
    #     signal: "GND"
    #   - color: Shield
    #     signal: "Shield"

connections:
  - # Verbindung der Datenleitungen
    - Raspberry_Pi: [1, 2, 3, 4]
    - USB_Cable: [1, 2, 3, 4]
  - # Verbindung der Datenleitungen
    - USB_Cable: [1, 2, 3, 1, 1, 2, 3, 1]
    - P1: [A4, A7, A6, A9, B4, B7, B6, B9]
  - # Verbindung von GND
    - USB_Cable: [4, 4, 4, 4] 
    - P1: [A1, A12, B1, B12]
  - # Verbindung des Schrims
    - Raspberry_Pi: [5]
    - USB_Cable: [s]
  - # Verbindung des Schrims
    - USB_Cable: [s]
    - P1: [S1]

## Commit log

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2024-04-24 added PCA9615 chip for differiantial I2C Communication
    [printhead-pcb.kicad_sch]
2024-04-24 add pwr, gnd 5V for di2c chip
    [fans.kicad_sch, io.kicad_sch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]
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2024-06-06 worked through errors and added data sheets
    [io.kicad_sch, printhead-pcb.kicad_sch, sensors.kicad_sch]
2024-06-06 created pi pcb and added ToDo Doc
    [I2C.kicad_sch, pi-shield-pcb.kicad_sch, printhead-pcb.kicad_sch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]
2024-06-07 had meeting with professor Jerman, created ToDos and updated a few Datasheets
    [I2C.kicad_sch, fans.kicad_sch, parts-list-printhead.xlsx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]
2024-06-08 added LED Driver and servos
    [led_driver.kicad_sch, motors.kicad_sch, printhead-pcb.kicad_sch]
2024-06-08 removed fan controller and added 2 fans for on off functionality.
    [fans.kicad_sch, led_driver.kicad_sch, motors.kicad_sch]
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2024-06-12 Buchse für Netzwerk kabel hinzugefügt, LED Driver überarbeitet, gpio überarbeitet
    [io.kicad_sch, led_driver.kicad_sch, motors.kicad_sch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]
2024-06-12 removed led driver, added RJ45 (data connector), fan 3. 4. on off
    [fans.kicad_sch, io.kicad_sch, motors.kicad_sch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]
2024-06-14 Beschriftungen im Schaltplan hinzugefügt
    [fans.kicad_sch, io.kicad_sch, motors.kicad_sch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]
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2024-07-29 added complete list of components for i2c
    [Elektronik.xlsx, fans.kicad_sch, motors.kicad_sch]
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2024-07-30 added new sheet for stacked pcb
    [Elektronik.xlsx, printhead-pcb.kicad_pcb, printhead-pcb.kicad_sch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]
2024-07-30 made first pcb design of module 1 with components on front and back
    [Elektronik.xlsx, fans.kicad_sch, io.kicad_sch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]
2024-07-30 second commit because autosave restored some things
    [fans.kicad_sch, io.kicad_sch, led_driver.kicad_sch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]
2024-07-30 made design with only one side full with components
    [printhead-pcb.kicad_pcb]
2024-07-30 functional, good design, but i need to make the data signal equally long
    [printhead-pcb.kicad_pcb]
2024-07-30 alle module mal grob gemacht, beim ersten noch den gpio hinzugefuegt, leider nicht auf einer layerseite untergebracht
    [printhead-pcb.kicad_pcb, printhead-pcb.kicad_sch, stackedPCB.kicad_sch]
2024-07-30 removed gpio, design with only one layer AND short and almost equally long data routes
    [printhead-pcb.kicad_pcb]
2024-07-30 very good layout, now reajusting the postions just a bit and making the traces thicker
    [printhead-pcb.kicad_pcb]
2024-07-30 working, good version with one layer and equally long signal routes, thicker traces and fitting text
    [printhead-pcb.kicad_pcb, stackedPCB.kicad_sch]
2024-07-30 repositioned text boxes just a bit more
    [printhead-pcb.kicad_pcb]
2024-07-30 finished module one design
    [printhead-pcb.kicad_pcb]
2024-07-30 prepared second module for tomorrow
    [printhead-pcb.kicad_pcb, stackedPCB.kicad_sch]
2024-07-31 tried out to link the two pcbs in schematic
    [printhead-pcb.kicad_pcb]
2024-07-31 tried python pcbnew, did not work
    [1.step, printhead-pcb.kicad_pcb, pyvenv.cfg]
2024-07-31 improved workflow and refractored
    [1.step, printhead-pcb.kicad_pcb]
2024-07-31 finished work, did not get step to convert to pdf file
    [printhead-pcb.kicad_pcb]
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2024-07-31 cleaned up printhead-pcb folder
    [BOM_072024.csv, deprecated_led_driver.kicad_sch, freerouting.dsn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]
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2024-07-31 deleted venv as it is not necessary anymore and updated workflow
    [pyvenv.cfg]
2024-08-01 better working pcb to pdf, now shortening it down more
    [pcb.dxf, pcb.step]
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2024-08-04 added first module into projet of second module
    [deprecated_led_driver.kicad_sch, fans.kicad_sch, io.kicad_sch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]
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2025-01-20 created 2nd mainboard kicad project
    will now transfer data from flux to kicad
    [2nd-mainboard-pcb.kicad_pcb, 2nd-mainboard-pcb.kicad_sch, WL-TMRC_3MM.step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]
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2025-01-21 added basic peripherie for the atmega and met with group
    incoming tasks: pads for unused ios for debugging use cases, add stepper driver, tsv diodes and condensators
    [2nd-mainboard-pcb.kicad_sch, atmega.kicad_sch, fans.kicad_sch]
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2025-02-14 edited the excel document further, imported components for layout
    [50-00619.STEP, ABNTC-0805.STEP, elektronik.xlsx]
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2025-02-24 updated a bit of the track widths, removed comments in schematic
    [2nd-mainboard-pcb.kicad_pcb, 2nd-mainboard-pcb.kicad_sch, atmega.kicad_sch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]
2025-02-24 kleine PCB Verbesserungen: edge.cuts fuer aussenkontur rund gemacht und cutout-funktion begonnen
    [2nd-mainboard-pcb.kicad_pcb]
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2025-02-25 layout: bahnenbreiten bearbeitet, neu geroutet bei 12V Buck, Bauteile teilweise ausgetauscht
    [2nd-mainboard-pcb.kicad_pcb]
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2025-02-25 DRC fehler behoben ca 200 stueck, jetzt gehts ans pcb ausschneiden
    [2nd-mainboard-pcb.kicad_pcb, atmega.kicad_sch, temperatur_messungen.kicad_sch]
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2025-02-25 bild hinzugefuegt, step-daten hinzugefuegt, abstandhalter in bom hinzugefuegt
    Todos: abstandhalter und neue male-stecker bei leistungsplatine muss im 3d modell geupdated werden, abstandhalter ins 3d modell dazu, 3d modell in inventor zusammenstaellen und als bild auf die plati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
    pinouts auf der platine machen
    [2nd-mainboard-pcb.kicad_pcb, elektronik_gespeicherte_Filter.xlsx]
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2025-03-02 stacked pcb reworked
    [2nd-mainboard-pcb.kicad_pcb, 2nd-mainboard-pcb.kicad_sch, atmega.kicad_sch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]
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2025-03-02 cleanup, want to get the workflow running soon in the future
    [elektronik_gespeicherte_Filter.xlsx, parts-list-printhead.xlsx]
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2025-03-03 wireviz konfiguration hinzugefuegt, muss von main pc noch geladen werden
    [2nd-mainboard-pcb.kicad_pcb, bom.csv, designators.csv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]
2025-03-03 wireviz-verkabelungen fuer stacked design hinzugefuegt und die der platine erneut ueberarbeitet
    [leistung_motoren.yml]
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

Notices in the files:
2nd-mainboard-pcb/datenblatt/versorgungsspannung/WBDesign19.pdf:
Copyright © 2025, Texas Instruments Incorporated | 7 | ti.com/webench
